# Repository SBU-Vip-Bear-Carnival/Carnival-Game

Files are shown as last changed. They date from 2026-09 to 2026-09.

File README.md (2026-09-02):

# Carnival Game

Firmware and hardware for an accessible carnival game built by Stony Brook's
**VIP BEAR** team for **United Cerebral Palsy of Long Island**.

A player presses a pressure plate to drive their track forward; first to the end
wins. It is built to be playable by children with limited strength and motor
control, which is why the plate threshold and the Mode 3 drift rate are treated
as accessibility settings rather than difficulty settings.

Arduino Mega 2560 — stepper-driven tracks, pressure-plate input, LED strip and
sound feedback, four game modes.

## Quick start

```bash
git clone https://github.com/SBU-Vip-Bear-Carnival/Carnival-Game.git
cd Carnival-Game
./tools/setup.sh
arduino-cli compile --profile mega firmware/carnival
```

If that compiles, you have a working setup. You do not need the Arduino IDE.

**Before you write any code, read [`docs/GIT-WORKFLOW.md`](docs/GIT-WORKFLOW.md).**
`main` is protected — all work happens on a branch and merges through a pull
request.

## Game modes

| Mode | Behaviour |
|---|---|
| 0 — Standby | Idle light pattern, motors parked |
| 1 — Single, easy | Each plate release advances the track one subdivision |
| 2 — Two player | Both tracks race |
| 3 — Single, hard | As mode 1, but the track drifts backward between presses |

Mode 3's drift rate is the accessibility knob — see `src/config/tuning.h`.

## Layout

```
firmware/carnival/     the sketch
  sketch.yaml          pinned board core + library versions
  src/config/          pins, tuning, types
  src/hardware/        one header per device
  src/game/            modes and menu
hardware/              CAD, wiring diagrams, BOM
tools/                 host-side scripts
tests/                 single-component bring-up sketches
docs/                  workflow, architecture, decisions
```

## Toolchain

Board core and every library are pinned in `firmware/carnival/sketch.yaml`, so
everyone and CI build the same thing. Adding a library means adding it there
with a version — see [`CONTRIBUTING.md`](CONTRIBUTING.md).

Currently: `arduino:avr 1.8.8`, TMCStepper 0.7.3, AccelStepper 1.64.0,
FastLED 3.10.5, DFRobotDFPlayerMini 1.0.6.

## Status

V1 was delivered to UCP in March 2026. This repo is **V2**, started Fall 2026:
new TPU pressure plates, a 5-button and LCD control panel, and firmware rebuilt
on a structure that more than one person can work in at once.

## History

V1 lived at `ssylviawolf-0/CARNIVALGAME-SOFTWARE` on a team member's personal
account. It is retired — kept read-only for reference, not developed further.
This repo does not carry its history.

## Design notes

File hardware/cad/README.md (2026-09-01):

# CAD

Source CAD and exported meshes for printed parts.

- Keep the **editable source** (`.f3d`, `.step`) next to the export (`.stl`).
  An STL alone cannot be modified, only replaced.
- Name by what the part is, not by version: `pressure-plate.f3d`, not
  `plate_v3_final.f3d`. Git holds the versions.
- Note the material and any print settings that matter in the PR.

Current work: TPU pressure plates and the 5-button UI panel. See
`docs/decisions/0001-tpu-pressure-plates.md` before printing anything.

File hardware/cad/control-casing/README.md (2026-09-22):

# control-casing — the UI panel enclosure, as received

Five STLs dropped in the team Discord on **2026-09-21** by **Jerry Wu**, who drew
them, committed here **verbatim**: the bytes and the filenames are exactly as
shared, nothing was re-exported, renamed or repaired. Same policy as the two bench sketches in
[`tests/`](../../../tests) — these are a record of what someone actually drew,
and a tidied version of that is worth less.

⚠ **This deliberately breaks the naming rule in [`../README.md`](../README.md)**
("name by what the part is, not by version"). That rule is for source CAD we
maintain; `casing body` vs `case_body` is how the files arrived, and renaming
them would destroy the only evidence of what supersedes what. Apply the rule to
the `.f3d`/`.step` when it lands — see *What is missing* below.

> [!important] The next drop is versioned: `v<main>.<major>.<minor>`
> Agreed in Discord on 2026-09-21 — main version, major change, minor change.
> Jerry already numbers internally (the assembly is `ControlCasing**2**`, and the
> next revision is **v2.4**); it just never reached the filenames. So
> `control-casing-v2.4-body.stl`, not `case_body.stl`.
>
> **Both rules are right, for different files.** `../README.md`'s "git holds the
> versions" is correct for source CAD the team maintains **in this repo**. It is
> wrong for STL exports arriving from one person's private CAD, where git holds
> only what we were sent and the filename is the only ordering information that
> travels with it. These are the second kind.

## They are one part, in one coordinate frame

Not five parts. Every file shares the same world origin and the same
**230.0 × 100.0 mm** outline, and each sits at its assembled height rather than
dropped to Z=0 — so they can be loaded together and they land in position.

| File | Dropped | Z range | Thickness | What it is |
|---|---|---|---|---|
| `ControlCasing2-Stem.stl` | 16:17 | 0 → 30 | — | **the whole assembly** as one closed mesh |
| `casing lid.stl` | 16:23 | 25 → 30 | 5.0 | face plate, rev A |
| `casing body.stl` | 16:24 | 0 → 23 | 5.0 wall | tray, rev A |
| `case_lid.stl` | 16:59 | 28 → 30 | 2.0 | face plate, rev B |
| `case_body.stl` | 16:59 | 0 → 28 | 2.0 wall | frame, rev B |

**Rev B is the newest** (16:59) and is the one to print if you print anything.
The revision went **5 mm walls → 2 mm** and the body from a closed tray to an
open frame, keeping the 30 mm overall height.

> [!note] Rev A does not close
> `casing body` tops out at Z=23 and `casing lid` starts at Z=25 — a **2 mm gap**
> with nothing in it. Either a lip is missing from the tray or the lid was moved
> and not re-mated. Rev B has no gap (28 → 28), so this looks like the bug rev B
> was drawn to fix. Left as-is; it is part of the record.

## Measured features

Taken off the mesh, not off a drawing. All ±0.1 mm, from cross-sections at
Z = 29.0 (lid) and Z = 1.0 / 14.0 (body).

- **Rectangular window — 80.2 × 36.4 mm**, in the left half of the face.
- **Square aperture — 30.2 × 30.2 mm**, to its right.
- **4 × ⌀15.0 mm through-holes**, centres inset **15.0 mm from both edges** at
  each corner, counterbored on the body.
- **Body opening — 170.0 mm** wide between the end flanges, which are 30 mm
  wide and carry the corner holes.

## ✅ The window confirms the display, independently

**80.2 × 36.4 mm is a 16×2 HD44780 module PCB (80 × 36 mm) with 0.2 mm
clearance.** Nobody had to say so — the geometry only fits that part.

That is a third independent confirmation of the display decided in ADR 0002
(`docs/decisions/0002-ui-panel-wiring.md`, which is **on PR #2 / `hw/ui-panel-pins`,
not yet on `main`** — hence no link from this branch): the team's wiring table
said parallel HD44780, the `test_track_panel` bench sketch ran one, and now the
enclosure is cut for one. **The 16×2-vs-20×4 and
I²C-vs-parallel question is closed.** A 20×4 is 98 × 60 mm and does not fit this
opening.

> [!warning] It is cut for the **PCB**, not the bezel
> 80 × 36 is the whole board, including the mounting ears and the header. The
> visible glass is about 64.5 × 16 mm and sits roughly centred. So this window
> shows the board, not just the screen, unless something covers the margin. Worth
> a look before it is printed — it may be intended, but a 0.2 mm clearance hole
> for a whole PCB also has nowhere to screw down.

## ❌❌ Rev B has no floor — and rev A did

**This is a regression, not a gap.** Cross-sections taken just above the base:

| File | At z = 1 mm | Verdict |
|---|---|---|
| `casing body` (rev A) | solid across the full width | **5 mm floor**, z 0→5 |
| `case_body` (rev B) | open through the middle | **no floor at all** |

Rev B — the newest, the one anyone would print — **deleted the base rev A had.**
It is an open frame, through from front to back.

⚠ **The panel mounts vertically**, so "down" for anything inside is toward the
open back, not toward a floor. Raised in Discord on 2026-09-21 (*"you put the
arduino in, there is nothing supporting it behind"*) and confirmed here against
the meshes. As it stands the contents are held in by the lid and by friction.

### Depth pulls the other way

| Revision | Clear internal depth | Floor? |
|---|---|---|
| Rev A | **~18 mm** (floor top z=5 → body top z=23) | ✅ |
| Rev B | **28 mm** (no floor → lid underside z=28) | ❌ |

Also asked in the same exchange — *"are you sure the box is deep enough for all
the headers and stuff"* — and the two revisions answer in opposite directions.
**Rev A is the one that is probably too shallow; rev B is the one deep enough.**
So the fix is **rev A's floor at rev B's depth**, not a choice between them.

⚠ **Nobody has measured the actual board.** For scale only: a Mega 2560 is ~1.6 mm
of PCB with ~3 mm of solder-side lead, a stacked female header stands ~8.5 mm
proud, and dupont housings on that header add roughly another 14–15 mm — call it
~20 mm before bend radius on the wire leaving the connector. **Those are
catalogue figures, not measurements of our hardware.** Put a caliper on the real
board with its jumpers fitted before cutting v2.4; it is the number this turns on.

## ❌ There are no button holes. Not one.

The face has the LCD window, the 30.2 mm square, and the four corner holes. That
is every opening in every one of the five files — checked on the meshes, not by
eye.

**The panel task on the team's list asks for a printed face carrying 5 buttons
and an LCD cut-out.** This is the LCD half only. Three readings, and the
repo cannot tell them apart:

1. **Unfinished** — the buttons are the next revision.
2. **The 30.2 mm square is the button cluster**, expecting a separate module or
   keypad behind it. 30.2 mm is too small for five 12 mm tactile switches with
   any spacing, so this only works if the buttons are a sub-assembly.
3. **The buttons are not on this panel at all** and mount elsewhere on the
   cabinet.

⚠ **This blocks printing either way**, and it collides with the *other* open
panel question: PR #2's `pins.h` names the five buttons `BTN_UP / DOWN / SELECT /
BACK / START` (a menu) while the bench sketch drives them as forward / stop /
slower / faster / reverse (direct motor control). **The legends go on this face.**
Whichever reading is right, the button semantics have to be settled before this
part is printed, not after.

## What the 30.2 mm square is, is unknown

Nothing in the repo describes a 30 mm square part. Candidates nobody has
confirmed: a 30 × 30 fan, a panel-mount connector, a keypad module, or — given
the `-Stem` in the assembly filename — a **30 mm square tube the panel mounts
on**, which would suit a height-adjustable panel for a seated player. **This is
speculation from a filename**, and it did **not** come up in the 2026-09-21
review, which covered mounting, depth and naming only. Still open; asked on the PR.

## What is missing

- **No source CAD.** `../README.md` asks for the `.f3d`/`.step` beside the
  export, because an STL can only be replaced, not modified. Five STLs and no
  editable file means **only Jerry can revise this** — which is worth saying out
  loud now that a revision is due the week of Sept 28.
- **No material, no print settings**, and no note of which printer. Note that
  [ADR 0001](../../../docs/decisions/0001-tpu-pressure-plates.md) governs the plates, not
  this — but the TPU printer request is still unanswered, so do not assume a
  machine is available.
- **No fit check against real hardware.** The LCD window is 0.2 mm on a PCB
  dimension read off a datasheet, not off the module the team owns.

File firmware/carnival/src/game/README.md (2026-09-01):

# Game logic

Modes and menu. What the game *does*, as opposed to `../hardware/`, which is how
to talk to a device.

Planned:

- `modes.h` — the four game modes, moved out of `carnival.ino` once they have
  real logic
- `menu.h` — the 5-button and LCD menu (V2)

Two rules:

- **Nothing here calls `delay()`.** A blocked loop misses a plate press, and to
  a player that reads as the game ignoring them. Check state and return.
- **Each mode owns its state struct** in `../config/types.h` and resets it
  through `reset()`, so a mode always starts clean.

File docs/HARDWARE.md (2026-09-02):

# Hardware

Arduino **Mega 2560**. The Mega is required, not incidental — the pin count and
the extra hardware serial ports (the DFPlayer uses `Serial1`) do not fit on a Uno.

See [`hardware/wiring/SCHEMATIC.md`](../hardware/wiring/SCHEMATIC.md) for the same
information as a diagram.

## Pin map

This table mirrors `firmware/carnival/src/config/pins.h`. **If you move a wire,
change both** — a pin map that only exists in documentation is how someone
spends an afternoon debugging a fault that is not there.

| Function | Pin | Notes |
|---|---|---|
| Stepper 1 STEP | 3 | track 1 |
| Stepper 1 DIR | 2 | |
| Stepper 1 ENABLE | 7 | LOW = enabled (TMC2209) |
| Stepper 2 STEP | 9 | track 2 |
| Stepper 2 DIR | 8 | |
| Stepper 2 ENABLE | 13 | ⚠ see below |
| Pressure plate 1 | A0 | analog |
| Pressure plate 2 | A1 | analog |
| Track 1 limit — start | 25 | `INPUT_PULLUP` |
| Track 1 limit — end | 23 | |
| Track 2 limit — start | 29 | |
| Track 2 limit — end | 27 | |
| Start button | 48 | `INPUT_PULLUP` |
| Start button LED | 53 | |
| Indicator LED 1 | 45 | |
| Indicator LED 2 | 37 | |
| WS2812B data | 6 | addressable strip, 40 LEDs |
| DFPlayer Mini | Serial1 (18/19) | TX/RX |

### ⚠ Pin 13 is a real defect, not a documentation error

`ENBL_PIN2` is on pin 13, which is the Mega's **built-in LED pin**. The
bootloader toggles it for roughly a second on every reset and every upload, and
the TMC2209's enable is active-LOW — so stepper driver 2 receives spurious
enable pulses at every power-up and every flash. The onboard LED and its series
resistor also load that line.

This is inherited from V1 and is documented here as the machine actually is.
**Moving it is a hardware change**, so it needs a rewire and a matching `pins.h`
edit in the same PR. Any free digital pin that is not 13 will do. Worth doing
before V2 ships; harmless to leave while bench testing.

Not yet wired — the V2 5-button panel and LCD. Add them to `pins.h` behind
`#ifndef` guards when they exist.

## Drivers and motors

TMC2209 stepper drivers. `tuning.h` carries the intended settings — sense
resistor 0.11 Ω, 600 mA RMS per motor, 2 microsteps — and 2 microsteps is a
deliberate trade, since more microstepping is quieter but loses torque and the
tracks need torque more than silence.

⚠ **None of that is applied yet.** No `TMC2209Stepper` is ever constructed, so
those three constants have no readers and the drivers run at their hardware and
jumper defaults. Wiring up UART control is V2 work. Until it lands, do not
assume the motors are current-limited to 600 mA.

## Pressure plates — the accessibility part

The plates are the whole point of the project. A plate that needs adult body
weight excludes the children the game is for.

- Read as analog on A0/A1; a press is a reading below `PRESSURE_THRESHOLD`.
- Must be held for `PLATE_MIN_PRESS_MS` (250 ms) to count, which rejects
  brushes and stumbles.
- `PLATE_DEBOUNCE_MS` (50 ms) filters contact bounce.

**Re-measure `PRESSURE_THRESHOLD` whenever the plate material changes.** TPU and
PLA do not read the same, and the threshold is not transferable between them.

## V1 lessons — do not rediscover these

- **PLA plates failed.** Printed in PLA they were too thick and too stiff to
  step on. This is why V2 is TPU. See `docs/decisions/`.
- **The printed button plate was abandoned** for a moulded rubber TV-remote-style
  pad, which worked better than anything printed.

## Bench setup

Testing on your own board with different pins? Do not edit `pins.h`:

```bash
cd firmware/carnival/src/config
cp pins.local.example.h pins.local.h
```

Override only the pins that differ. The file is gitignored, CI never sees it,
and deleting it returns you to the cabinet's real wiring.

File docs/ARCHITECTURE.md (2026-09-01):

# Architecture

## The shape of it

```
carnival.ino          setup() and loop(); dispatches on the current mode
  src/config/         what the machine IS
    pins.h              wiring
    tuning.h            calibration
    types.h             enums, per-mode state structs
  src/hardware/       how to talk to each device -- one header per device
  src/game/           what the game DOES -- modes, menu
```

Arduino compiles everything under a sketch's `src/` recursively, so the nesting
is free.

## Why it is split this way

V1 had a single `config.h` holding pins, tuning constants and type definitions
together. Every change touched that one file, so every change conflicted, and two
people refactoring in parallel produced two half-versions of the project that were
never reconciled.

The split follows how often things change:

- `pins.h` — changes when a wire moves. Rare, and always paired with a hardware
  change.
- `tuning.h` — changes constantly during bring-up. Expect churn here.
- `types.h` — should almost never change.

Keeping them apart means a wiring fix and a calibration tweak do not land in the
same file and fight.

## Control flow

`loop()` dispatches on `currentMode`:

| Mode | Function |
|---|---|
| `MODE_STANDBY` | `runStandby()` |
| `MODE_SINGLE_EASY` | `runSingleEasy()` |
| `MODE_TWO_PLAYER` | `runTwoPlayer()` |
| `MODE_SINGLE_HARD` | `runSingleHard()` |

Each mode owns a state struct in `types.h` (`Mode1State`, `Mode2State`,
`Mode3State`) with a `reset()`. Modes are non-blocking — they check state and
return. **Nothing calls `delay()` in a game loop**; a blocked loop means a plate
press gets missed, which reads to a player as the game ignoring them.

## Mode 3 and accessibility

Mode 3 drifts the track backward between presses. The drift constants in
`tuning.h` are the difficulty knob for the entire game, and difficulty here is an
accessibility setting: `DRIFT_GRACE_PERIOD_MS` is how long a player gets after a
press before the track starts pulling back. A player who cannot press quickly is
excluded by a short grace period.

Change these with a real player in mind, not a fast one.

## What V2 adds

- TPU pressure plates (PLA failed — see `docs/decisions/`)
- A 5-button UI panel with an LCD, replacing the single start button
- Audio via DFPlayer Mini on `Serial1` — see `src/hardware/audio.h`
- Possibly a HUB75 RGB matrix; V1 had a working demo but it never merged

## Where V1's code went

This repo does not carry V1's history. The audio system here is ported from it
with a compile error fixed. If you need to look something up, the old repo is
`ssylviawolf-0/CARNIVALGAME-SOFTWARE`, retired and read-only.

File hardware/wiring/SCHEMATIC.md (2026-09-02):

# The wiring, as a picture

This is the whole machine on one page. **You do not need to know electronics to
read it** — every box is a physical part you can hold, and every arrow is a wire.

The numbers on the arrows are the pin numbers on the Arduino. They match
[`firmware/carnival/src/config/pins.h`](../../firmware/carnival/src/config/pins.h)
exactly. If they ever disagree, `pins.h` is right and this page is stale — say
something.

---

## The whole thing

Arrows point the way information travels. Things on the left tell the Arduino
what the player did; things on the right are how the game answers.

```mermaid
flowchart LR
    subgraph IN["WHAT THE PLAYER DOES"]
        P1["Pressure plate 1<br/>(player 1 steps here)"]
        P2["Pressure plate 2<br/>(player 2 steps here)"]
        BTN["Start button"]
        LS1["Track 1 limit switches<br/>start + end"]
        LS2["Track 2 limit switches<br/>start + end"]
    end

    MEGA{{"ARDUINO MEGA 2560<br/>the brain"}}

    subgraph OUT["HOW THE GAME ANSWERS"]
        D1["TMC2209 driver 1"]
        D2["TMC2209 driver 2"]
        M1(["Stepper motor 1<br/>moves track 1"])
        M2(["Stepper motor 2<br/>moves track 2"])
        STRIP["WS2812B LED strip<br/>40 lights"]
        DF["DFPlayer Mini<br/>+ speaker"]
        LEDS["Indicator LEDs"]
    end

    P1 -- "A0 analog" --> MEGA
    P2 -- "A1 analog" --> MEGA
    BTN -- "48" --> MEGA
    LS1 -- "25 start / 23 end" --> MEGA
    LS2 -- "29 start / 27 end" --> MEGA

    MEGA -- "STEP 3 / DIR 2 / EN 7" --> D1
    MEGA -- "STEP 9 / DIR 8 / EN 13" --> D2
    D1 --> M1
    D2 --> M2
    MEGA -- "6 data" --> STRIP
    MEGA -- "Serial1 = 18 TX / 19 RX" --> DF
    MEGA -- "53 / 45 / 37" --> LEDS
```

---

## What each part actually does

### The pressure plates — the important bit

Two sheets with a thin gap and a pressure-sensitive material (**Velostat**)
between them. Standing on it squeezes the sheets together and its **resistance
drops**.

That is why they are on **A0 and A1**, the *analog* pins. A normal pin only
answers "is it on or off." An analog pin answers "how hard," on a scale of 0 to
1023 — and how hard is exactly what we need, because the whole project exists to
be playable by children who cannot stamp.

The firmware calls it a press when the reading drops below `PRESSURE_THRESHOLD`
and stays there for 250 ms. The 250 ms is deliberate: it ignores a foot brushing
past, without demanding a stomp.

> ⚠ **Re-measure the threshold whenever the plate material changes.** TPU and PLA
> do not read the same numbers. The old value is not transferable.

### The limit switches — how the cart knows where it is

A stepper motor can count its own steps, but it has no idea where it *started*.
So each track has two little switches, one at each end. On power-up the cart
drives until it bumps one, and that becomes position zero.

They are wired `INPUT_PULLUP`, which is a way of saying the Arduino holds the
wire high by itself and the switch's job is just to yank it to ground. It saves a
resistor per switch.

> From the V1 build log: the switch must be struck by the **cart platform, not
> the wheels**. Getting that wrong cost an afternoon and a reprint.

### The steppers and their drivers

The Arduino does not drive the motors directly — it hasn't the muscle. It sends
three small signals to a **TMC2209 driver**, which does the actual pushing:

| Signal | Meaning |
|---|---|
| `STEP` | one pulse = one step |
| `DIR` | high or low = forwards or backwards |
| `ENABLE` | **LOW turns the motor on** (backwards from what you'd guess) |

### The lights and the sound

The **WS2812B strip** is 40 LEDs on a single data wire — each light listens for
its turn in the message, which is why one pin can control all forty.

The **DFPlayer Mini** is a small MP3 player with an SD card. The Arduino tells it
"play track 9" and it does the rest. Track numbers are the filenames on the card:
`0009.mp3` is track 9. The list lives in
[`audio.h`](../../firmware/carnival/src/hardware/audio.h).

It talks over `Serial1` — a second serial port. This is the reason the project
needs a **Mega** and not a Uno: a Uno has exactly one serial port and the USB
cable is already using it.

---

## ⚠ One known defect: pin 13

`ENABLE` for driver 2 is on **pin 13**, which is also the Mega's built-in LED
pin.

Every time the board resets or you upload code, the bootloader blinks that LED
for about a second. Because enable is active-LOW, driver 2 sees that blink as
**"turn on, turn off, turn on"** — so motor 2 twitches at every power-up and
every flash.

This came from V1 and is documented here as the machine truly is. Fixing it
means physically moving one wire to any free digital pin that isn't 13, and
editing `pins.h` in the same pull request. Harmless while bench testing, worth
fixing before V2 is delivered.

---

## The startup sequence

```mermaid
sequenceDiagram
    participant Player
    participant Mega as Arduino
    participant Motor
    participant Switch as Limit switch

    Mega->>Motor: drive slowly toward the start
    Motor-->>Switch: cart arrives, presses it
    Switch-->>Mega: "here!"
    Mega->>Mega: call this position zero
    Note over Mega: now it knows where the cart is
    Player->>Mega: press start
    Mega->>Player: lights + sound, game begins
```

---

## If you change the wiring

1. Move the wire.
2. Edit `pins.h`.
3. Edit the table in [`docs/HARDWARE.md`](../../docs/HARDWARE.md).
4. Edit the diagram above.
5. Put all of it in **one** pull request.

Four places sounds like a lot. It is the difference between the next person
trusting this page and the next person losing an afternoon to a fault that was
never there.

**Photographs of the real wiring are worth as much as any diagram — take them and
add them to this folder.**

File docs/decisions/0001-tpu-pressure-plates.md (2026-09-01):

# 0001 — TPU pressure plates instead of PLA

**Date:** Fall 2026
**Status:** accepted, pending material approval

## Context

V1's pressure plates were 3D printed in PLA. In use they were **too thick and too
stiff to step on** — which for a game whose players are children with cerebral
palsy is not a rough edge, it is the product failing at its one job.

A printed button plate was also tried and abandoned; a moulded rubber
TV-remote-style pad worked better than anything printed.

## Decision

Print V2 plates in **TPU**. Flexible filament gives travel and a lower actuation
force at the same geometry.

## Consequences

- **`PRESSURE_THRESHOLD` in `tuning.h` must be re-measured.** TPU and PLA do not
  read the same on the analog pin. Carrying the V1 number over would silently
  reproduce the V1 problem.
- Blocked on a TPU material request (asked 2026-08-31). **Do not slice anything
  for TPU until that is approved.**
- TPU needs a direct-drive extruder; not every printer available will do it.

## Rejected

- **Thinner PLA** — reduces stiffness but cracks under a stepped load.
- **Keep PLA, lower the threshold in firmware** — treats a mechanical problem as
  a software one. The plate would still be stiff; the sensor would just be
  twitchier.

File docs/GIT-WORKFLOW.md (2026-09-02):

# How we use git

You do not need to understand git to follow this. Copy the commands.

The rule that matters: **nobody commits to `main`.** You make a branch, you push
it, you open a pull request, someone glances at it, it merges. That is the whole
system. Everything below is detail.

---

## Why we bother

The previous version of this project lived in one repo with no rules. What
happened:

- `main` stopped compiling in May 2026 — a missing comma — and **nobody noticed
  for four months**, because nothing checked.
- Two people refactored in parallel and neither branch ever merged. The project
  ended up with two half-versions and no whole one.
- Someone made branches called `dummy_main` and `dummy_cleanup`, because they
  wanted somewhere safe to experiment and did not know a branch already is that.
- Three `wip/` branches sat untouched for six months and died there.

None of that was anyone being careless. It is what happens without guardrails.
Now there are guardrails.

---

## One-time setup

```bash
git clone https://github.com/SBU-Vip-Bear-Carnival/Carnival-Game.git
cd Carnival-Game
./tools/setup.sh
```

`setup.sh` checks you have `arduino-cli`, installs a hook that stops you pushing
to `main` by accident, creates your `tools/.env`, and then compiles the firmware
to prove the toolchain works. If it fails at that last step, stop and fix it —
you do not have a working setup yet.

---

## Every single time you work

**1. Start from an up-to-date `main`.**

```bash
git checkout main
git pull
```

**2. Make a branch. Name it `type/what-you-are-doing`.**

```bash
git checkout -b feat/audio-volume-buttons
```

Types: `feat` (new thing), `fix` (broken thing), `hw` (wiring/CAD), `docs`,
`test`, `chore`.

**3. Work. Commit as you go — small commits are good.**

```bash
git add .
git commit -m "Add volume up/down handling to the UI panel"
```

**4. Push it.**

```bash
git push -u origin feat/audio-volume-buttons
```

The first push on a branch needs `-u`. After that, just `git push`.

**5. Open a pull request.** GitHub prints a link when you push — click it. Fill
in the template. Say what you changed and whether you tested it on the cabinet.

**6. Wait for the build.** A robot compiles your branch. Green check = it
builds. Red X = it does not, and you need to fix it before anyone reviews.

**7. Get one approval, then squash-merge.** The branch deletes itself.

**8. Go back to step 1.** Your local `main` is now behind — pull before you
start the next thing.

---

## Writing a commit message

Say what changed and why it matters. Present tense.

Good:

```
Lower the plate threshold to 450 — the TPU prototype reads lower than PLA
Stop the track drifting during the grace period
Add the DFPlayer wiring diagram
```

Bad — all of these are real commits from the old repo:

```
puts the demo in the folder
Create lights folder
Update HEADER.md
```

The test: in six months, will someone scanning the log know whether this commit
is the one that broke the game? `Update HEADER.md` fails that test.

---

## When it goes wrong

This section exists so nobody ever needs a `dummy_main` again.

### "I want to throw away everything I just did"

Your branch is a scratch pad. Deleting it costs nothing and touches nobody.

```bash
git checkout main
git branch -D my-messy-branch          # local
git push origin --delete my-messy-branch   # if you already pushed it
```

`main` is untouched. This is what branches are *for* — experiment freely.

### "I want to undo my last commit but keep the code"

```bash
git reset --soft HEAD~1
```

Your changes are back to uncommitted. Edit, re-commit.

### "I want to throw away my uncommitted changes"

```bash
git restore .
```

⚠ This one really does delete work, and git cannot get it back. It is the only
command here that bites.

### "I committed to `main` by accident"

The hook should have stopped you, but if you got past it and have not pushed:

```bash
git branch my-work            # save it to a branch
git reset --hard origin/main  # put main back
git checkout my-work          # carry on properly
```

### "Someone else changed the same file — I have a conflict"

```bash
git checkout main
git pull
git checkout my-branch
git merge main
```

Git marks the clashes in the file like this:

```
<<<<<<< HEAD
your version
=======
their version
>>>>>>> main
```

Delete the `<<<<<<<`, `=======`, `>>>>>>>` lines and leave the code you want —
often a bit of both. Then:

```bash
git add .
git commit
```

**If you are not sure which version is right, ask the person who wrote the other
one.** Guessing here is how the old repo ended up with two half-versions.

### "My branch is really old and everything conflicts"

That is the actual lesson of the old `wip/` branches. **A branch older than about
two weeks should be merged or closed.** If it has drifted that far, it is usually
faster to start a fresh branch off current `main` and copy your changes in.

### "I broke something and I don't know what"

```bash
git log --oneline -10       # recent commits
git diff main               # everything your branch changed
```

Then ask. Nobody minds.

---

## Things you must not do

- **Never `git push --force` to `main`.** It rewrites history for everyone and
  can destroy other people's work. Force-pushing *your own* branch is fine.
- **Never commit `pins.local.h`.** It is your bench wiring. It is gitignored; if
  you force it in, CI will fail on purpose.
- **Never commit a fix you have not compiled.** That is precisely the four-month
  bug.

---

## Cheat sheet

| I want to… | Command |
|---|---|
| Start something new | `git checkout main && git pull && git checkout -b feat/thing` |
| See what I changed | `git status` and `git diff` |
| Save my work | `git add . && git commit -m "..."` |
| Send it up | `git push` (first time: `git push -u origin BRANCH`) |
| Which branch am I on? | `git branch --show-current` |
| Throw this branch away | `git checkout main && git branch -D BRANCH` |
| Undo last commit, keep code | `git reset --soft HEAD~1` |
| Build it | `arduino-cli compile --profile mega firmware/carnival` |

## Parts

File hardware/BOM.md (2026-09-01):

# Bill of materials

What the cabinet is built from. Fill in as parts are confirmed — an approximate
list that exists beats a perfect one that does not.

| Part | Qty | Notes |
|---|---|---|
| Arduino Mega 2560 | 1 | Uno will not fit — pin count and Serial1 |
| TMC2209 stepper driver | 2 | UART, 0.11 Ω sense resistor |
| Stepper motor | 2 | one per track |
| Limit switch | 4 | start + end, per track |
| Pressure plate | 2 | TPU for V2 — PLA failed, see docs/decisions/ |
| WS2812B LED strip | 1 | 40 LEDs |
| DFPlayer Mini | 1 | on Serial1, needs a microSD card |
| Speaker | 1 | |
| Start button + LED | 1 | being replaced by the 5-button panel in V2 |
| LCD | 1 | V2, model not chosen |
| Push button | 5 | V2 UI panel |

Add supplier and cost as they are ordered — VIP purchases need a record.

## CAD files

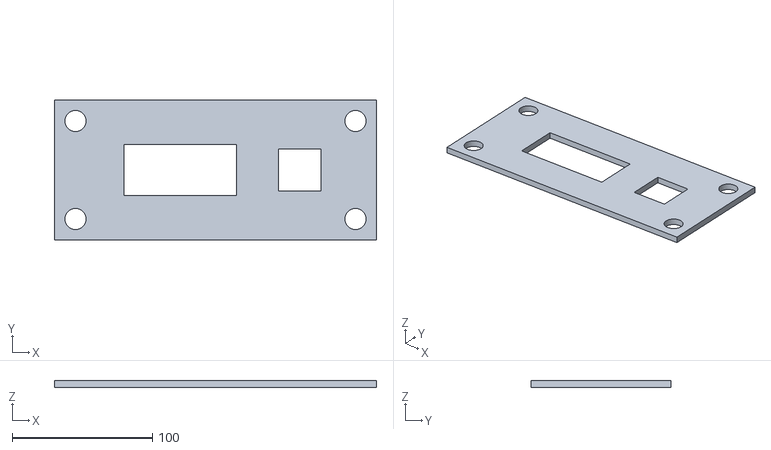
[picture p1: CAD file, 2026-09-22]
hardware/cad/control-casing/casing lid.stl
230.0 x 100.0 x 5.00

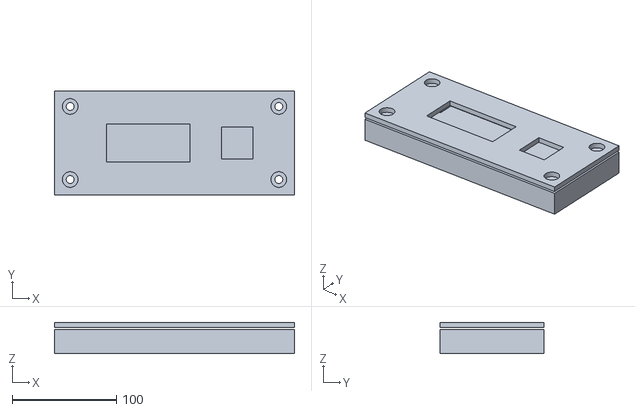
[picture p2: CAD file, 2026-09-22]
hardware/cad/control-casing/ControlCasing2-Stem.stl
230.0 x 100.0 x 30.0

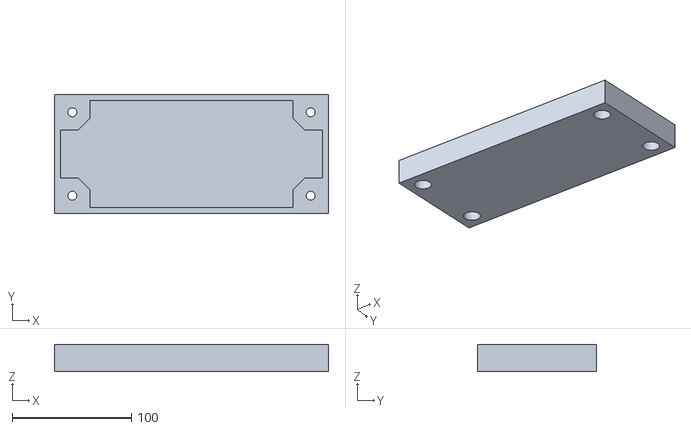
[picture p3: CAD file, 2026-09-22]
hardware/cad/control-casing/casing body.stl
230.0 x 100.0 x 23.0

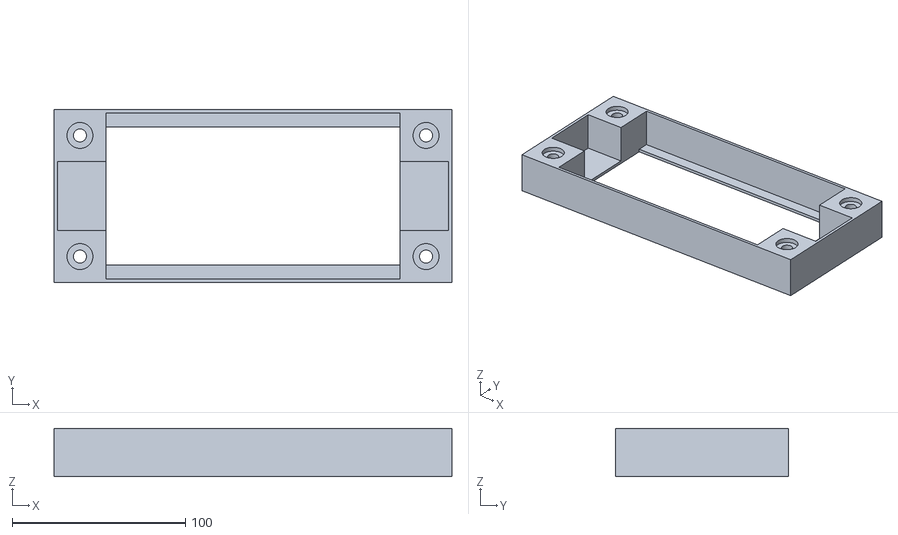
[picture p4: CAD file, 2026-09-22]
hardware/cad/control-casing/case_body.stl
230.0 x 100.0 x 28.0

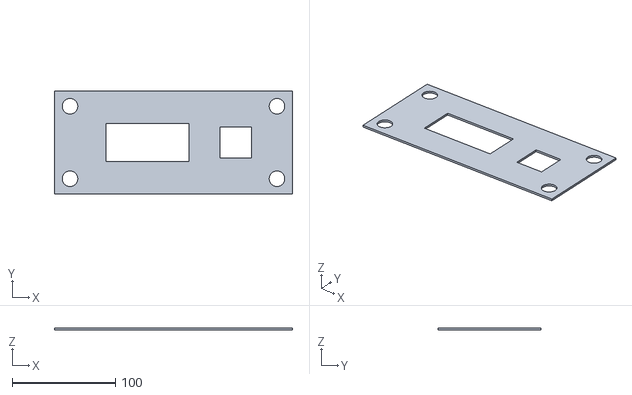
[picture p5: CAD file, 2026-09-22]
hardware/cad/control-casing/case_lid.stl
230.0 x 100.0 x 2.00

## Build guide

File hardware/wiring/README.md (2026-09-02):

# Wiring

Diagrams and photos of how the cabinet is actually wired.

**Start with [`SCHEMATIC.md`](SCHEMATIC.md)** — the whole machine as one diagram,
written so you can read it without an electronics background.

**This must agree with `firmware/carnival/src/config/pins.h`.** If you move a
wire, update both in the same pull request. A pin map that only exists in
documentation is how the next person loses an afternoon to a fault that is not
there.

Photos of the real wiring are worth as much as a clean diagram — take them.

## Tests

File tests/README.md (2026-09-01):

# Bring-up sketches

One sketch per component, each proving a single piece of hardware works before
it goes anywhere near the game loop. When something breaks on the cabinet, these
are how you find out whether it is the wiring or the logic.

Each test is its own sketch folder — the folder name must match the `.ino`:

```
tests/test_pressure_plate/test_pressure_plate.ino
```

**Give each one its own `sketch.yaml`** (copy `firmware/carnival/sketch.yaml`
and trim it to the libraries that test needs). **Keep the profile named `mega`** —
CI runs `--profile mega` for every test, so a renamed profile fails the build. CI compiles every test that has
one and skips those that do not, so a test without a pinned profile is a test
nobody is checking.

Worth having: pressure plate, limit switch, single stepper, LED strip, DFPlayer,
LCD, button panel.

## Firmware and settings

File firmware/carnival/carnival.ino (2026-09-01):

//
// carnival.ino — VIP BEAR accessible carnival game, V2.
//
// Arduino Mega 2560. Build it with the pinned toolchain, not the IDE's
// "whatever you happen to have installed":
//
//   arduino-cli compile --profile mega firmware/carnival
//
// Structure:
//   src/config/    pins, tuning, types      -- what the machine IS
//   src/hardware/  drivers for each device  -- how to talk to it
//   src/game/      modes and menu           -- what the game DOES
//
// This is the V2 skeleton. It brings the hardware up and compiles clean; the
// game logic is the Fall 2026 work. Add to it on a branch, never on main.
//

#include <Arduino.h>
#include <AccelStepper.h>
#include <FastLED.h>
#include <TMCStepper.h>   // pinned and installed, but no driver is constructed
                          // yet -- see the TMC block in src/config/tuning.h

#include "src/config/pins.h"
#include "src/config/tuning.h"
#include "src/config/types.h"
#include "src/hardware/audio.h"

// --- Globals -----------------------------------------------------------
AccelStepper track1(AccelStepper::DRIVER, STEP_PIN1, DIR_PIN1);
AccelStepper track2(AccelStepper::DRIVER, STEP_PIN2, DIR_PIN2);

CRGB        leds[NUM_LEDS];
AudioSystem audio;
GameMode    currentMode = MODE_STANDBY;

// --- Setup -------------------------------------------------------------
void setup() {
  Serial.begin(115200);

  // DFPlayer Mini lives on Serial1 (Mega pins 18/19).
  Serial1.begin(9600);
  audio.begin(Serial1);

  pinMode(ENBL_PIN1, OUTPUT);
  pinMode(ENBL_PIN2, OUTPUT);
  digitalWrite(ENBL_PIN1, LOW);   // LOW = driver enabled on the TMC2209
  digitalWrite(ENBL_PIN2, LOW);

  pinMode(TRK1_LS1, INPUT_PULLUP);
  pinMode(TRK1_LS2, INPUT_PULLUP);
  pinMode(TRK2_LS1, INPUT_PULLUP);
  pinMode(TRK2_LS2, INPUT_PULLUP);

  pinMode(STRT_PIN,  INPUT_PULLUP);
  pinMode(START_LED, OUTPUT);
  pinMode(LED1,      OUTPUT);
  pinMode(LED2,      OUTPUT);

  track1.setMaxSpeed(MAX_STEPPER_SPEED);
  track1.setAcceleration(STEPPER_ACCELERATION);
  track2.setMaxSpeed(MAX_STEPPER_SPEED);
  track2.setAcceleration(STEPPER_ACCELERATION);

  FastLED.addLeds<WS2812B, DATA_PIN, GRB>(leds, NUM_LEDS);
  FastLED.clear(true);

  Serial.println(F("carnival: ready"));
}

// --- Loop --------------------------------------------------------------
void loop() {
  switch (currentMode) {
    case MODE_STANDBY:      runStandby();     break;
    case MODE_SINGLE_EASY:  runSingleEasy();  break;
    case MODE_TWO_PLAYER:   runTwoPlayer();   break;
    case MODE_SINGLE_HARD:  runSingleHard();  break;
  }
}

// --- Mode stubs --------------------------------------------------------
// TODO(V2): implement against the TPU plates and the 5-button + LCD panel.
// Each of these should move into src/game/modes.h once it has real logic.

void runStandby() {
  // Idle attract pattern; wait for the start button.
}

void runSingleEasy() {
  // One player, one track. Each plate release advances one subdivision.
}

void runTwoPlayer() {
  // Both tracks race.
}

void runSingleHard() {
  // Like easy, but the track drifts backward between presses.
  // DRIFT_* in tuning.h is the accessibility knob -- see that file.
}

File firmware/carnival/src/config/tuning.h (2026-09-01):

#pragma once
//
// tuning.h — calibration for the physical cabinet.
//
// This file IS committed, deliberately. There is one machine, and a threshold
// that only exists on one person's laptop is how the game stops working the
// week they are away. Change a value here, open a PR, say what you measured.
//
// If a number in here is wrong, the game feels wrong. Treat it as real code.
//

#include <Arduino.h>

// --- TMC2209 stepper drivers -------------------------------------------
// ⚠ NOT APPLIED YET. Nothing constructs a TMC2209Stepper, so these three are
// currently dead constants and the drivers run at their hardware/jumper
// defaults. Wiring up UART control is V2 work; until then do not trust the
// current limit below to be what the motors are actually getting.
const float TMC_R_SENSE          = 0.11f;   // sense resistor on the driver board
const int   TMC_CURRENT_MA       = 600;     // per-motor RMS current
const int   TMC_MICROSTEPS       = 2;

// --- Motion ------------------------------------------------------------
const int   MAX_STEPPER_SPEED    = 2000;
const int   STEPPER_ACCELERATION = 1000;
const int   NORMAL_SPEED         = 1000;
const int   SLOW_SPEED           = 400;
const int   BOUNDS_SPEED         = 800;     // speed while seeking a limit switch

// --- Pressure plates ---------------------------------------------------
// PRESSURE_THRESHOLD is the accessibility-critical number. Too high and a
// child who cannot press hard cannot play at all. Re-measure it whenever the
// plate material changes -- TPU and PLA do not read the same.
const int           PRESSURE_THRESHOLD = 500;
const unsigned long PLATE_DEBOUNCE_MS  = 50;
const unsigned long PLATE_MIN_PRESS_MS = 250;   // ignore brushes and stumbles

// --- Track -------------------------------------------------------------
const int           TRACK_SUBDIVISIONS     = 5;    // presses needed to win
const unsigned long CALIBRATION_TIMEOUT_MS = 15000;

// --- Mode 3 backward drift ---------------------------------------------
// This is the difficulty knob for the whole game. Raising DRIFT_SPEED or
// DRIFT_STEPS_PER_INTERVAL makes Mode 3 harder; DRIFT_GRACE_PERIOD_MS is how
// long a player gets after a press before the track starts pulling back.
const int           DRIFT_SPEED              = 200;
const int           DRIFT_INTERVAL_MS        = 500;
const int           DRIFT_STEPS_PER_INTERVAL = 100;
const unsigned long DRIFT_GRACE_PERIOD_MS    = 1000;

// --- Lighting ----------------------------------------------------------
const int   NUM_LEDS = 40;

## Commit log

2026-09-01 Scaffold the V2 repo — pinned toolchain, CI, and a workflow beginners can follow
    V1 lived on a team member's personal account with no guardrails. Its main branch
    stopped compiling on 2026-05-07 (a missing comma in the AudioTrack enum) and
    nobody noticed for four months, because nothing checked. Two refactors diverged
    and never merged, leaving two half-versions and no whole one. This is the
    structure that makes those failures loud instead of silent.
    - sketch.yaml pins the board core and every library to an exact version, so a
    build is the same build on every laptop and in CI
    - build.yml compiles on every PR — the backstop that was missing
    - pins.h / tuning.h / types.h split V1's single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
    [audio.h, carnival.ino, tuning.h]
2026-09-01 Put the org and repo permissions in a script, not in someone's memory
    The settings that actually enforce the workflow — base permission read, teams
    with write, squash-only, auto-delete branches, and the main ruleset — are easy
    to click once and impossible to audit later. Writing them as a script means the
    next person can read what the rules are and re-apply them.
    Creating the organization itself stays manual; GitHub has no API for it on
    github.com. Everything after that step is here.
    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
2026-09-01 Fix what the audit found: a latent header break, four script bugs, three false docs
    Nothing here was caught by the build, which is the point — a green compile only
    proves the one path the .ino takes today.
    pins.h and tuning.h used A0/A1 without including <Arduino.h>. That compiles only
    because carnival.ino includes Arduino.h first; the moment a header under src/
    includes pins.h first — which src/game/README.md says is the plan — it breaks.
    Verified the fix by compiling a sketch that includes pins.h with nothing before
    it.
    Documented rather than silently changed: ENBL_PIN2 is pin 13, the Mega's
    built-in LED pin. The bootloader toggles it for about a second on every reset
    and upload, a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
    [carnival.ino, tuning.h]
2026-09-02 Draw the wiring, for people who cannot read a pin table
    HARDWARE.md already had the pin map, but a table is not a picture and half
    this team is mechanical or biomedical. SCHEMATIC.md renders on GitHub with
    no tooling: inputs on the left, the Mega in the middle, motors, lights and
    sound on the right, every arrow labelled with its real pin number.
    Explains the parts in plain language too -- why the plates are analog and
    not digital, why limit switches exist at all, why ENABLE is active-LOW, and
    why the pin 13 collision makes motor 2 twitch on every upload.
2026-09-02 Two sub-teams, Electronics and Design
    Corrected by Lionel. The scaffold assumed electronics/software/mechanical,
    which is a shape borrowed from bigger projects; this team does not have a
    separate software sub-team -- the electronics side writes the firmware.
    bootstrap-org.sh now creates two teams, and CODEOWNERS maps firmware and
    config to electronics, hardware and CAD to design. Those rules stay
    commented out until the teams have members, or every PR deadlocks waiting
    on an empty team.
2026-09-22 Add the Discord control-casing STLs, and measure what they actually are
    Five STLs shared in the team Discord on 2026-09-21, committed verbatim --
    bytes and filenames exactly as received, same policy as the two bench
    sketches in tests/. They are not five parts: all five share one coordinate
    frame and one 230.0 x 100.0 mm outline, and each sits at its assembled
    height, so they load together and land in position. Two revisions plus a
    whole-assembly export. Rev B (16:59) is newest -- 5 mm walls thinned to 2 mm.
    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
    [ControlCasing2-Stem.stl, case_body.stl, case_lid.stl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]
2026-09-22 Credit Jerry, adopt the version scheme, and record the missing floor
    The 2026-09-21 Discord review answered two of this README's open items and
    raised a fault worth more than either.
    Jerry Wu drew these, so the README says so. The next drop is versioned
    v<main>.<major>.<minor> by agreement -- next revision is v2.4. Noted why
    that does not contradict ../README.md's "name by what the part is": git
    holds the versions for source CAD we maintain here, and holds nothing for
    STL exports out of someone's private CAD, where the filename is the only
    ordering information that travels with the file.
    The fault: rev B has no floor and rev A did. Cross-sections at z=1 are
    solid across on rev A and open o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
